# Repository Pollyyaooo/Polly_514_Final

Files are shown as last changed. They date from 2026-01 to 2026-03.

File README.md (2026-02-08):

# EmoTrace
#### MSTI TECHIN 514 Final Project           
#### 01/06/2026-03/06/2026

## Project Overview

This project investigates emotion sensing as a process of externalization rather than interpretation.
It measures physiological arousal through galvanic skin response (GSR) and expresses it using a
stepper-motor-driven physical needle display.

Instead of identifying discrete emotions or presenting numerical readouts, the system focuses on
how affective states unfold over time. Changes in arousal are rendered as continuous physical
motion, allowing inertia, gradual transitions, and recovery to remain visible rather than being
collapsed into instantaneous values.

The project is composed of two physically separated devices: a sensing device and a display device,
connected wirelessly via BLE. The sensing device captures and processes physiological signals, while
the display device externalizes these signals as a slow, glanceable, and non-intrusive physical
artifact. Through this separation, the project explores how emotional states can be felt,
noticed, and reflected upon, without being classified or explained away.

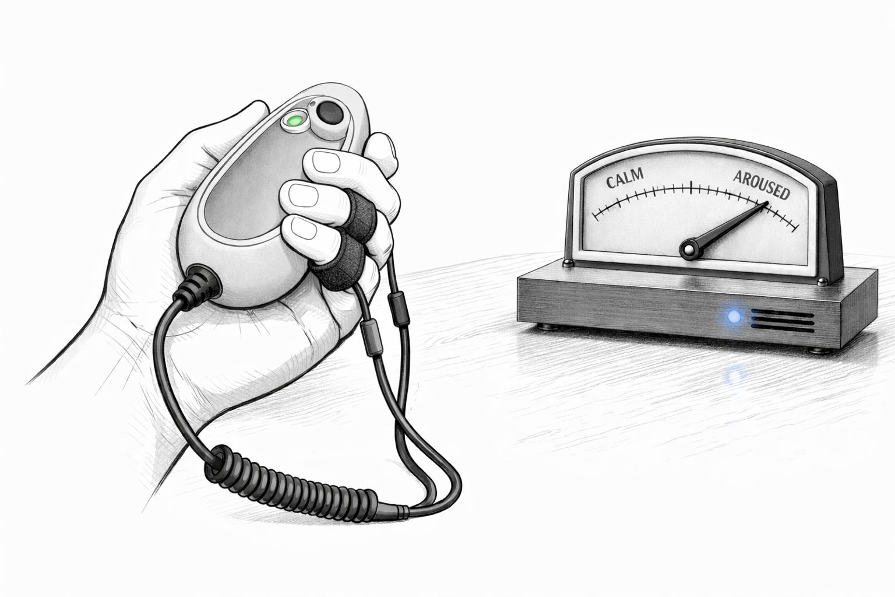
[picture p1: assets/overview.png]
overview


## System Architecture

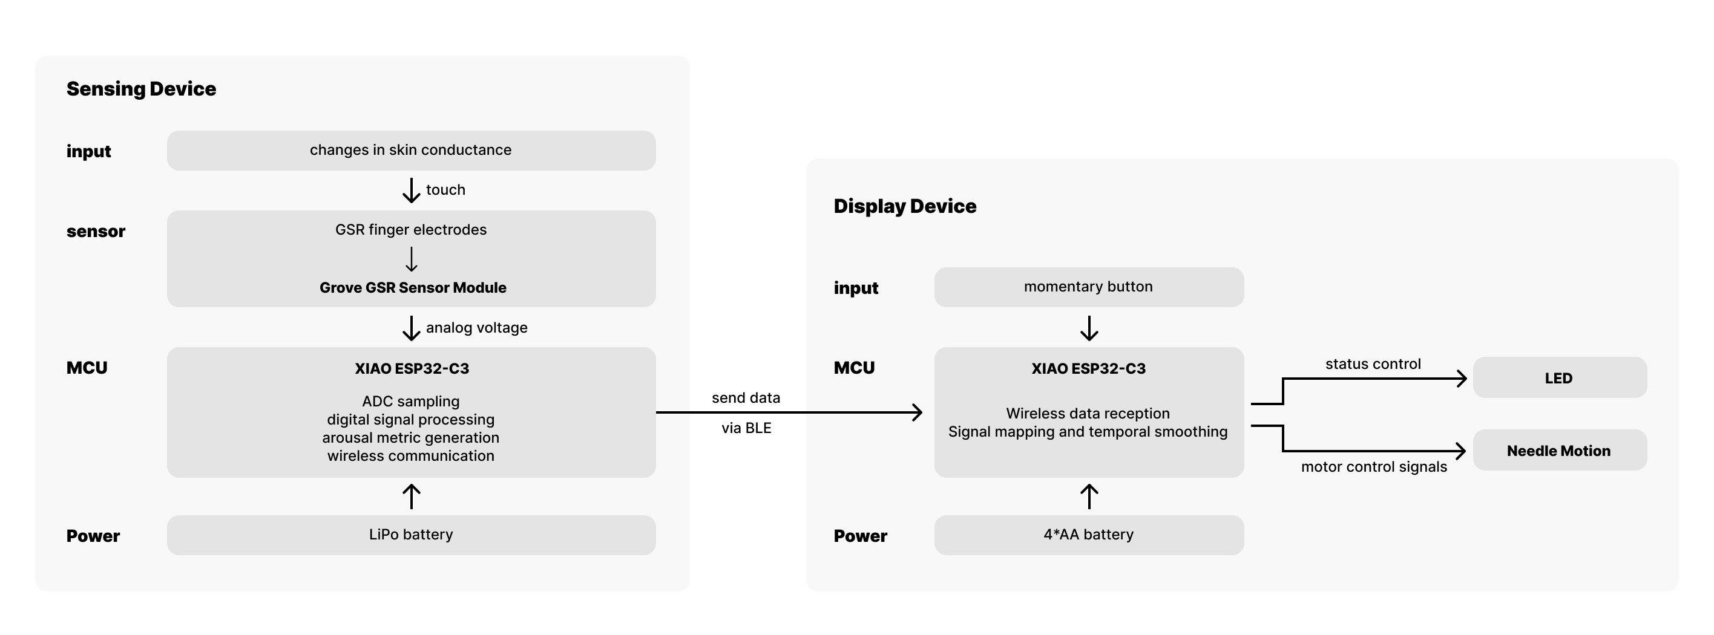
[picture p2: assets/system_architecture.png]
System Architecture


**Sensing Device**
- Captures electrodermal activity via finger electrodes and a GSR sensor module
- Performs basic digital signal processing (filtering, baseline normalization)
- Transmits a continuous arousal indicator via BLE

**Display Device**
- Receives arousal data wirelessly
- Drives a stepper-motor-based gauge needle as the primary expressive output
- Provides minimal user input and status indication
- Is implemented on a custom-designed PCB

## Battery Estimation

### Display Device
Spreadsheet link:  
https://1drv.ms/x/c/3520740a59bca320/IQBtffllcoQcSJlxG03brPWNAZ11j2MDRlCTxOjXR5vgqAk?e=tpQcXu

### Sensing Device
Spreadsheet link:  
https://1drv.ms/x/c/3520740a59bca320/IQDMDjtJkVfMQYsOUzpoie-YAZGBVunHImL63yKkG8l4-dY?e=yHCJq8

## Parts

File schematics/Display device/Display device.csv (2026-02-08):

Source: | /Users/yaoyitong/Documents/Pollyyaooo-Polly_514_Final/schematics/Display device/Display device.kicad_sch
Date: | 2026-02-04T01:42:55-0800
Tool: | Eeschema 9.0.5
Generator: | /Applications/KiCad/KiCad.app/Contents/SharedSupport/plugins/bom_csv_grouped_by_value_with_fp.py
Component Count: | 11
Ref | Qnty | Value | Cmp name | Footprint | Description | Vendor | DNP
C1 | 1 | 100uF | C | Capacitor_SMD:C_0805_2012Metric_Pad1.18x1.45mm_HandSolder | Unpolarized capacitor
C2 | 1 | 0.1uF | C | Capacitor_SMD:C_0805_2012Metric_Pad1.18x1.45mm_HandSolder | Unpolarized capacitor
D1 | 1 | LED | LED | LED_SMD:LED_0805_2012Metric_Pad1.15x1.40mm_HandSolder | Light emitting diode
J1 | 1 | stepper motor | Conn_01x04_Pin | Connector_PinHeader_2.54mm:PinHeader_1x04_P2.54mm_Vertical | Generic connector, single row, 01x04, script generated
R1 | 1 | 330Ω | R | Resistor_SMD:R_0805_2012Metric_Pad1.20x1.40mm_HandSolder | Resistor
R2, R3, R4, R5 | 4 | 47Ω | R_4 | Resistor_SMD:R_0805_2012Metric_Pad1.20x1.40mm_HandSolder | Resistor
SW1 | 1 | SW_Push | SW_Push | Button_Switch_SMD:SW_Push_1P1T_NO_E-Switch_TL3301NxxxxxG | Push button switch, generic, two pins
U1 | 1 | XIAO ESP32C3 | XIAO_ESP32 | GIX_ESP32:XIAO_ESP32

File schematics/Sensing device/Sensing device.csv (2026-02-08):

Source: | /Users/yaoyitong/Documents/Pollyyaooo-Polly_514_Final/schematics/Sensing device/Sensing device.kicad_sch
Date: | 2026-02-04T01:48:26-0800
Tool: | Eeschema 9.0.5
Generator: | /Applications/KiCad/KiCad.app/Contents/SharedSupport/plugins/bom_csv_grouped_by_value_with_fp.py
Component Count: | 7
Ref | Qnty | Value | Cmp name | Footprint | Description | Vendor | DNP
C1 | 1 | 10uF | C | Capacitor_SMD:C_0805_2012Metric_Pad1.18x1.45mm_HandSolder | Unpolarized capacitor
C2, C3 | 2 | 0.1uF | C | Capacitor_SMD:C_0805_2012Metric_Pad1.18x1.45mm_HandSolder | Unpolarized capacitor
J2 | 1 | Grove_GSR | Conn_01x04_Pin | Connector_JST:JST_PH_S4B-PH-SM4-TB_1x04-1MP_P2.00mm_Horizontal | Generic connector, single row, 01x04, script generated
R1 | 1 | 220Ω | R | Resistor_SMD:R_0805_2012Metric_Pad1.20x1.40mm_HandSolder | Resistor
SW1 | 1 | SW_Push | SW_Push | Button_Switch_SMD:SW_Push_1P1T_NO_E-Switch_TL3301NxxxxxG | Push button switch, generic, two pins
U1 | 1 | XIAO ESP32C3 | XIAO_ESP32 | GIX_ESP32:XIAO_ESP32

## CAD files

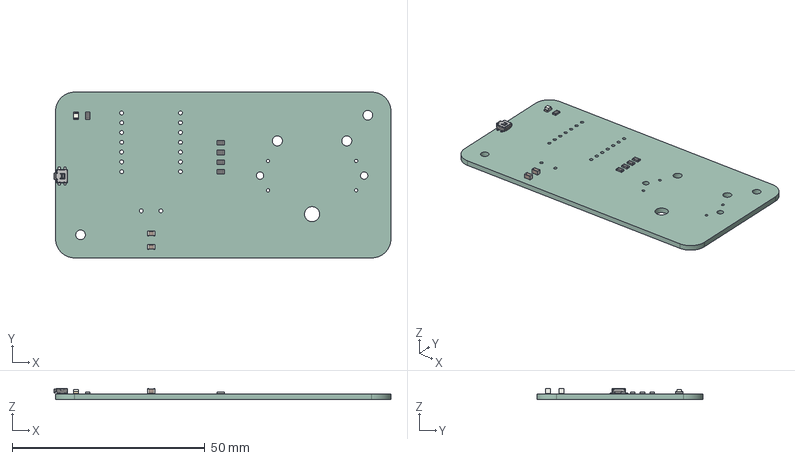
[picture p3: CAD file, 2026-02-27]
schematics/Display device/Display device.step
87.4 x 43.0 x 2.95 mm
LED_0805_2012Metric
R_0805_2012Metric x 5
SW_SPST_EVQP7A
C_0805_2012Metric x 2
Display device_PCB

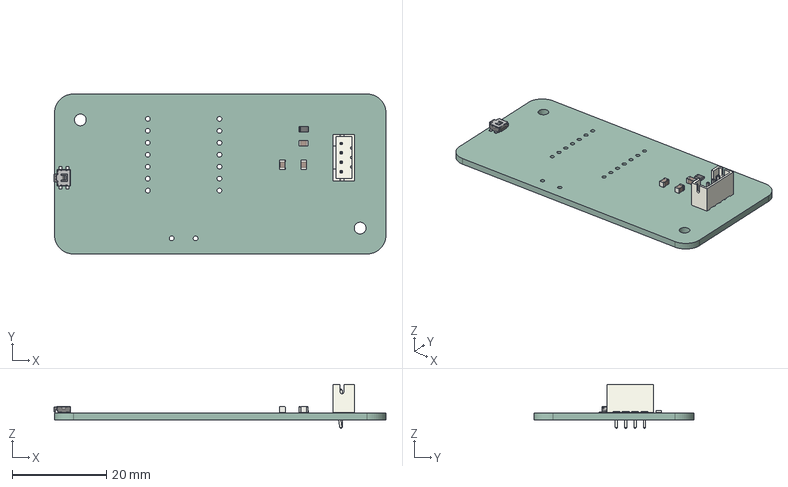
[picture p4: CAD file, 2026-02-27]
schematics/Sensing device/Sensing device.step
70.6 x 34.0 x 9.40 mm
SW_SPST_EVQP7A
C_0805_2012Metric x 3
JST_PH_B4B-PH-K_1x04_P2.00mm_Vertical
R_0805_2012Metric
Sensing device_PCB

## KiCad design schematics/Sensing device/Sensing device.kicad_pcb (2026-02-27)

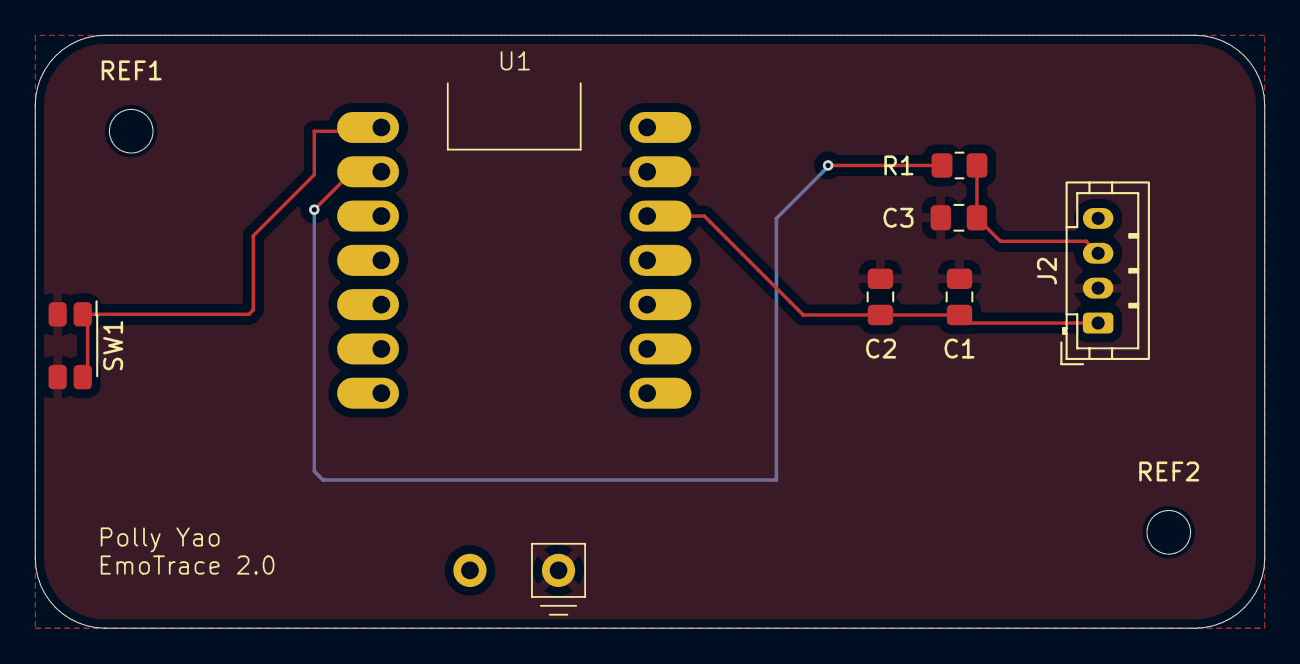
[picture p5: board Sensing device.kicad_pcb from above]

Board: 2 copper layers, 70.5 x 34.0 mm, 9 parts (0 on the bottom side), 5 nets.

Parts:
C1: 10uF; C_0805_2012Metric_Pad1.18x1.45mm_HandSolder
C2, C3: 0.1uF; C_0805_2012Metric_Pad1.18x1.45mm_HandSolder
J2: Grove_GSR; JST_PH_B4B-PH-K_1x04_P2.00mm_Vertical
R1: 220Ω; R_0805_2012Metric_Pad1.20x1.40mm_HandSolder
REF1, REF2: MountingHole_2.5mm
SW1: SW_Push; SW_SPST_EVQP7A
U1: XIAO ESP32C3; XIAO_ESP32

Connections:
+3V3: C1.1, C2.1, J2.1, U1.12 (3V3)
/CAL_BTN: SW1.1, U1.1 (GPIO1_A0_D0)
/GSR_SIG: R1.2, U1.2 (GPIO2_A1_D1)
GND: C1.2, C2.2, C3.1, J2.2, SW1.2, U1.13 (GND), U1.16 (-BATT)
unnamed: C3.2, J2.3, R1.1

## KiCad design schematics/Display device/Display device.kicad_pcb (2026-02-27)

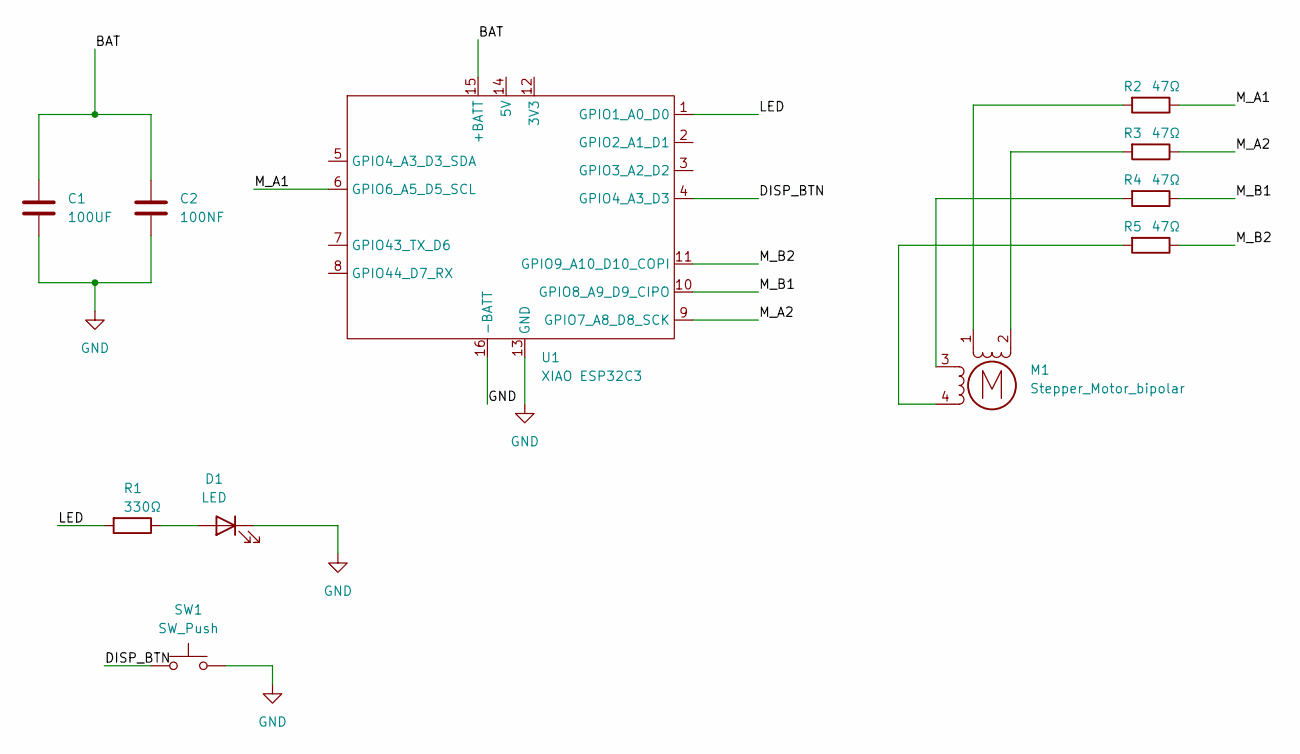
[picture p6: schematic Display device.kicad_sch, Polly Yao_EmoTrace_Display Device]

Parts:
C1: 100UF; C_0805_2012Metric_Pad1.18x1.45mm_HandSolder
C2: 100NF; C_0805_2012Metric_Pad1.18x1.45mm_HandSolder
D1: LED; LED_0805_2012Metric_Pad1.15x1.40mm_HandSolder
M1: Stepper_Motor_bipolar; x27_stepper_two_holes
R1: 330Ω; R_0805_2012Metric_Pad1.20x1.40mm_HandSolder
R2, R3, R4, R5: 47Ω; R_0805_2012Metric_Pad1.20x1.40mm_HandSolder
SW1: SW_Push; SW_SPST_EVQP7A
U1: XIAO ESP32C3; XIAO_ESP32

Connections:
/BAT: C1.1, C2.1, U1.15 (+BATT)
/DISP_BTN: SW1.1, U1.4 (GPIO4_A3_D3)
/LED: R1.2, U1.1 (GPIO1_A0_D0)
/M_A1: R2.1, U1.6 (GPIO6_A5_D5_SCL)
/M_A2: R3.1, U1.9 (GPIO7_A8_D8_SCK)
/M_B1: R4.1, U1.10 (GPIO8_A9_D9_CIPO)
/M_B2: R5.1, U1.11 (GPIO9_A10_D10_COPI)
GND: C1.2, C2.2, D1.1 (K), SW1.2, U1.13 (GND), U1.16 (-BATT)
unnamed: D1.2 (A), R1.1
unnamed: M1.2 (-), R3.2
unnamed: M1.1, R2.2
unnamed: M1.3, R4.2
unnamed: M1.4, R5.2

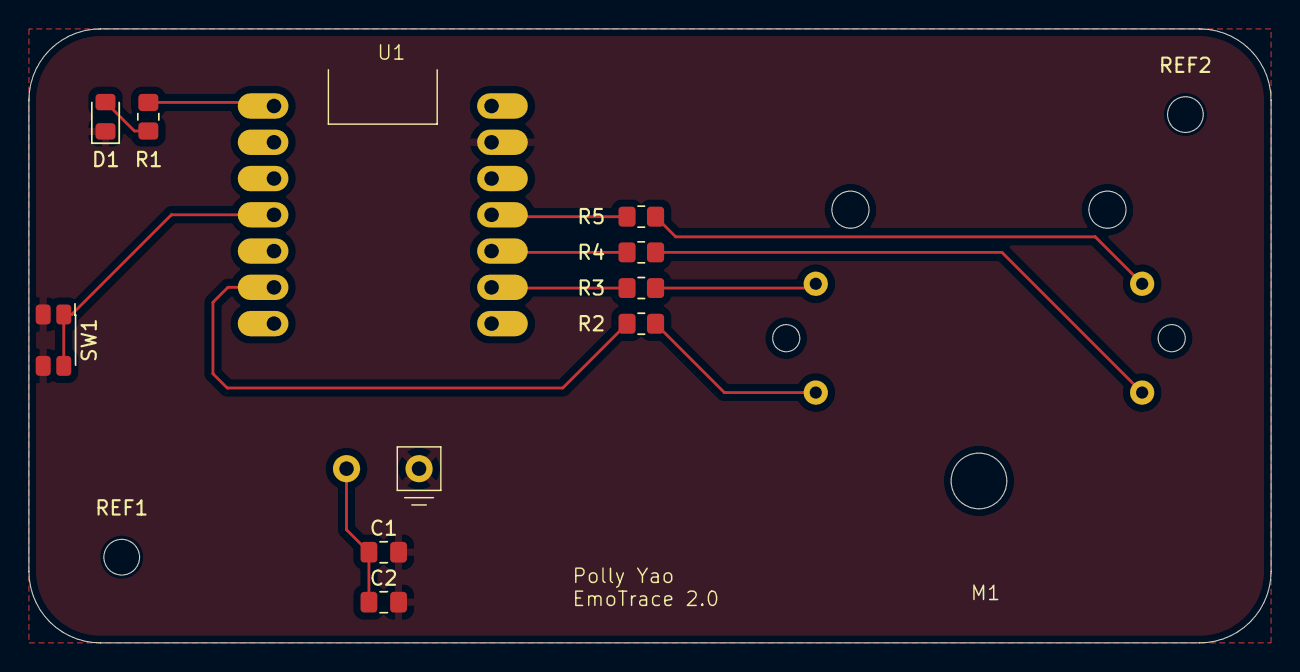
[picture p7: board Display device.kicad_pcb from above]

Board: 2 copper layers, 87.0 x 43.0 mm, 13 parts (0 on the bottom side), 13 nets.

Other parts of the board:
REF1, REF2: MountingHole_2.5mm

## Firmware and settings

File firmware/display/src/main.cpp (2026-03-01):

#include <Arduino.h>
#include <BLEDevice.h>
#include <BLEUtils.h>
#include <BLEScan.h>
#include <BLEAdvertisedDevice.h>

// 你可以把服务UUID和特征UUID替换为你的服务器的UUID
static BLEUUID serviceUUID("72e8ce72-67f1-4114-8412-1b0e1b35e0b1");
static BLEUUID charUUID("59ce0b83-f1c9-4229-9227-c6bd61ca7797");

static boolean doConnect = false;
static boolean connected = false;
static boolean doScan = false;
static BLERemoteCharacteristic* pRemoteCharacteristic;
static BLEAdvertisedDevice* myDevice;

// 线序定义
#define A1 9
#define A2 10
#define B1 8
#define B2 5

int stepIndex = 0;

// 步进电机的步进序列（半步驱动）
const uint8_t seq[4][4] = {
  {1, 0, 1, 0},
  {0, 1, 1, 0},
  {0, 1, 0, 1},
  {1, 0, 0, 1}
};

// 当前步进位置
int currentStep = 0;

// 目标角度（由 BLE 传入）
volatile int targetAngle = 0;
volatile bool needMove = false;

// 通知回调函数
static void notifyCallback(
  BLERemoteCharacteristic*,
  uint8_t* pData,
  size_t length,
  bool)
{
    if (length == 1) {
        uint8_t value = pData[0];

        // 映射值到 0-180 度
        int angle = map(value, 0, 100, 0, 180);

        Serial.print("Received: ");
        Serial.println(value);
        Serial.print("Move to angle: ");
        Serial.println(angle);

        targetAngle = angle;
        needMove = true;  // 设置标志，表示需要开始移动电机
    }
}

// 电机步进函数
void stepMotor(int dir)
{
  stepIndex = (stepIndex + dir + 4) % 4;  // 确保步进序列循环

  digitalWrite(A1, seq[stepIndex][0]);
  digitalWrite(A2, seq[stepIndex][1]);
  digitalWrite(B1, seq[stepIndex][2]);
  digitalWrite(B2, seq[stepIndex][3]);

  delay(6);  // 控制步进速度
}

// 电机移动到指定角度
void moveToAngle(int angle)
{
  // 将角度映射到步进
  int steps = map(angle, 0, 180, 0, 2048);  // 假设2048步为一圈
  int diff = steps - currentStep;

  // 计算步进方向
  int dir = (diff > 0) ? 1 : -1;

  // 移动电机
  for (int i = 0; i < abs(diff); i++) {
    stepMotor(dir);
  }

  currentStep = steps;  // 更新当前步进位置
}

// BLE 客户端回调函数
class MyClientCallback : public BLEClientCallbacks {
  void onConnect(BLEClient* pclient) {}
  void onDisconnect(BLEClient* pclient) {
    connected = false;
    Serial.println("onDisconnect");
  }
};

// BLE 扫描回调函数
class MyAdvertisedDeviceCallbacks : public BLEAdvertisedDeviceCallbacks {
  void onResult(BLEAdvertisedDevice advertisedDevice) {
    Serial.print("BLE Advertised Device found: ");
    Serial.println(advertisedDevice.toString().c_str());

    // 只连接包含目标服务UUID的设备
    if (advertisedDevice.haveServiceUUID() && advertisedDevice.isAdvertisingService(serviceUUID)) {
      BLEDevice::getScan()->stop();
      myDevice = new BLEAdvertisedDevice(advertisedDevice);
      doConnect = true;
    }
  }
};

// 连接到 BLE 服务器
bool connectToServer() {
  Serial.print("Forming a connection to ");
  Serial.println(myDevice->getAddress().toString().c_str());

  BLEClient* pClient = BLEDevice::createClient();
  Serial.println(" - Created client");

  pClient->setClientCallbacks(new MyClientCallback());

  bool connectionResult = pClient->connect(myDevice);
  if (!connectionResult) {
    Serial.println(" - Failed to connect to server");
    return false;
  }

  Serial.println(" - Connected to server");
  pClient->setMTU(517); // 设置客户端请求最大MTU

  BLERemoteService* pRemoteService = pClient->getService(serviceUUID);
  if (pRemoteService == nullptr) {
    Serial.print("Failed to find our service UUID: ");
    Serial.println(serviceUUID.toString().c_str());
    pClient->disconnect();
    return false;
  }
  Serial.println(" - Found our service");

  pRemoteCharacteristic = pRemoteService->getCharacteristic(charUUID);
  if (pRemoteCharacteristic == nullptr) {
    Serial.print("Failed to find our characteristic UUID: ");
    Serial.println(charUUID.toString().c_str());
    pClient->disconnect();
    return false;
  }
  Serial.println(" - Found our characteristic");

  if (pRemoteCharacteristic->canNotify()) {
    pRemoteCharacteristic->registerForNotify(notifyCallback);
  }

  connected = true;
  return true;
}

// 扫描设备并连接
void checkServerStatus() {
  Serial.println("Scanning for server...");
  BLEDevice::getScan()->start(5, false);

  if (doConnect) {
    if (connectToServer()) {
      Serial.println("Connected to BLE Server.");
    } else {
      Serial.println("Failed to connect.");
    }
    doConnect = false;
  }
}

void setup() {
  Serial.begin(115200);
  Serial.println("Starting Arduino BLE Client application...");
  BLEDevice::init("");

  pinMode(A1, OUTPUT);
  pinMode(A2, OUTPUT);
  pinMode(B1, OUTPUT);
  pinMode(B2, OUTPUT);

  BLEScan* pBLEScan = BLEDevice::getScan();
  pBLEScan->setAdvertisedDeviceCallbacks(new MyAdvertisedDeviceCallbacks());
  pBLEScan->setInterval(1349);
  pBLEScan->setWindow(449);
  pBLEScan->setActiveScan(true);
}

void loop() {
  if (!connected) {
    checkServerStatus();
  }

  if (needMove) {
    needMove = false;
    moveToAngle(targetAngle);
  }

  delay(10);
}

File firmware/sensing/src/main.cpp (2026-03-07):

#include <Arduino.h>
#include <BLEDevice.h>
#include <BLEServer.h>
#include <BLEUtils.h>
#include <BLE2902.h>

// ---------------- BLE ----------------
BLEServer* pServer = NULL;
BLECharacteristic* pCharacteristic = NULL;

bool deviceConnected = false;
bool oldDeviceConnected = false;

// Use the same UUIDs as your display device
#define SERVICE_UUID        "72e8ce72-67f1-4114-8412-1b0e1b35e0b1"
#define CHARACTERISTIC_UUID "59ce0b83-f1c9-4229-9227-c6bd61ca7797"

// ---------------- GSR ----------------
// Use A1 for analog input from Grove GSR signal pin
#define GSR_PIN A1

// Moving average filter settings
const int FILTER_SIZE = 10;
int gsrBuffer[FILTER_SIZE] = {0};
int bufferIndex = 0;
long bufferSum = 0;

int rawGsr = 0;
int filteredGsr = 0;
int lastFilteredGsr = 0;

// Output value sent over BLE (0-100)
int emotionValue = 0;

// Timing
unsigned long previousMillis = 0;
unsigned long sampleInterval = 300;  // default idle interval

// ---------------- Modes ----------------
enum DeviceMode {
  MODE_SLEEP,
  MODE_IDLE,
  MODE_ACTIVE
};

DeviceMode currentMode = MODE_SLEEP;

// Threshold for detecting stronger signal change
const int ACTIVE_DELTA_THRESHOLD = 8;

// These two values may need calibration for your own sensor
const int GSR_MIN = 300;
const int GSR_MAX = 800;

class MyServerCallbacks : public BLEServerCallbacks {
  void onConnect(BLEServer* pServer) {
    deviceConnected = true;
  }

  void onDisconnect(BLEServer* pServer) {
    deviceConnected = false;
  }
};

// Moving average filter
int updateMovingAverage(int newValue) {
  bufferSum -= gsrBuffer[bufferIndex];
  gsrBuffer[bufferIndex] = newValue;
  bufferSum += gsrBuffer[bufferIndex];

  bufferIndex = (bufferIndex + 1) % FILTER_SIZE;

  return bufferSum / FILTER_SIZE;
}

// Update software mode based on connection + signal activity
void updateMode() {
  int delta = abs(filteredGsr - lastFilteredGsr);

  if (!deviceConnected) {
    currentMode = MODE_SLEEP;
    sampleInterval = 1000;   // slowest when disconnected
  } 
  else if (delta >= ACTIVE_DELTA_THRESHOLD) {
    currentMode = MODE_ACTIVE;
    sampleInterval = 100;    // fastest when signal changes more
  } 
  else {
    currentMode = MODE_IDLE;
    sampleInterval = 300;    // moderate update rate
  }
}

const char* modeToString(DeviceMode mode) {
  switch (mode) {
    case MODE_SLEEP: return "SLEEP";
    case MODE_IDLE:  return "IDLE";
    case MODE_ACTIVE:return "ACTIVE";
    default:         return "UNKNOWN";
  }
}

void setup() {
  Serial.begin(115200);
  delay(2000);
  Serial.println("Starting BLE GSR sensing device...");

  pinMode(GSR_PIN, INPUT);

  // Initialize filter buffer with first reading
  int initial = analogRead(GSR_PIN);
  for (int i = 0; i < FILTER_SIZE; i++) {
    gsrBuffer[i] = initial;
    bufferSum += initial;
  }
  filteredGsr = initial;
  lastFilteredGsr = initial;

  BLEDevice::init("EmoSense");
  pServer = BLEDevice::createServer();
  pServer->setCallbacks(new MyServerCallbacks());

  BLEService* pService = pServer->createService(SERVICE_UUID);

  pCharacteristic = pService->createCharacteristic(
    CHARACTERISTIC_UUID,
    BLECharacteristic::PROPERTY_READ |
    BLECharacteristic::PROPERTY_NOTIFY
  );

  pCharacteristic->addDescriptor(new BLE2902());

  uint8_t initValue = 0;
  pCharacteristic->setValue(&initValue, 1);

  pService->start();

  BLEAdvertising* pAdvertising = BLEDevice::getAdvertising();
  pAdvertising->addServiceUUID(SERVICE_UUID);
  pAdvertising->setScanResponse(true);
  pAdvertising->setMinPreferred(0x06);
  pAdvertising->setMinPreferred(0x12);

  BLEDevice::startAdvertising();
  Serial.println("BLE advertising started.");
}

void loop() {
  unsigned long currentMillis = millis();

  if (currentMillis - previousMillis >= sampleInterval) {
    previousMillis = currentMillis;

    // Read raw sensor value
    rawGsr = analogRead(GSR_PIN);

    // Store previous filtered value before updating
    lastFilteredGsr = filteredGsr;

    // DSP: moving average filter
    filteredGsr = updateMovingAverage(rawGsr);

    // Map filtered GSR to 0-100
    emotionValue = map(filteredGsr, GSR_MIN, GSR_MAX, 0, 100);
    emotionValue = constrain(emotionValue, 0, 100);

    // Update state machine
    updateMode();

    // Print debug info
    Serial.print("Raw: ");
    Serial.print(rawGsr);
    Serial.print(" | Filtered: ");
    Serial.print(filteredGsr);
    Serial.print(" | Emotion: ");
    Serial.print(emotionValue);
    Serial.print(" | Mode: ");
    Serial.println(modeToString(currentMode));

    // Send only when connected
    if (deviceConnected) {
      uint8_t data = emotionValue;
      pCharacteristic->setValue(&data, 1);
      pCharacteristic->notify();

      Serial.print("Notify value: ");
      Serial.println(emotionValue);
    }
  }

  // Handle reconnection advertising
  if (!deviceConnected && oldDeviceConnected) {
    delay(200);
    pServer->startAdvertising();
    Serial.println("Restart advertising");
    oldDeviceConnected = deviceConnected;
  }

  if (deviceConnected && !oldDeviceConnected) {
    Serial.println("Client connected");
    oldDeviceConnected = deviceConnected;
  }
}

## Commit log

2026-01-26 schematic add
    [Display device.kicad_pcb, Display device.kicad_sch, Sensing device.kicad_pcb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]
2026-01-26 update sensing device
    [Sensing device.kicad_sch]
2026-01-27 update display device
2026-02-02 kicad update
    [Sensing device.csv, Sensing device.kicad_pcb, Sensing device.kicad_sch]
2026-02-04 update code
    [Display device-B_Cu.gbr, Display device-B_Mask.gbr, Display device-B_Paste.gbr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]
2026-02-27 sche update
    [Display device-B_Cu.gbr, Display device-B_Mask.gbr, Display device-B_Paste.gbr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]
